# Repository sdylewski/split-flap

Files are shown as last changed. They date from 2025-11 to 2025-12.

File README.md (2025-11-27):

-# Split-Flap
+# Split-Flap
+
(   )
+
+Split Flap Display
+
+This fork builds on the brilliant [original project](https://github.com/Dave19171/split-flap) by
+[David Königsmann](https://github.com/Dave19171) and adds a modern web UI, OTA updates,
+message scheduling, a WiFi setup portal, diagnostics and numerous firmware
+improvements while keeping the 3D-printable mechanical design.
+
+## Feature Highlights
+
+- Multi-mode web UI (text, countdown, date, clock) with scheduling and OTA
+- Non-blocking ESPMaster firmware that keeps HTTP requests responsive
+- Built-in WiFi setup portal (AP mode) plus optional static IP/direct mode
+- LED error indicator (ESP-01S), page-load debug logs and copyable serial logs
+- Message splitting for long strings, newline support and REST endpoints
+
+## Documentation
+
+All project documentation now lives under [`docs/`](./docs). Start here:
+
+| Topic | Description |
+| --- | --- |
+| [`docs/README.md`](./docs/README.md) | Docs hub + quick start |
+| [`docs/printing.md`](./docs/printing.md) | BOM, screw list, printed parts, flap tips |
+| [`docs/hardware-build.md`](./docs/hardware-build.md) | PCB soldering, unit assembly, enclosure |
+| [`docs/software.md`](./docs/software.md) | Firmware setup, calibration, debugging, usage |
+| [`docs/SplitFlapInstructions.md`](./docs/SplitFlapInstructions.md) | Legacy PDF converted to Markdown |
+
+## Repository Structure
+
+```
+.
+├── docs/                 # Documentation hub
+├── ESPMaster/            # ESP-01S firmware + web assets
+├── Unit/                 # Arduino Nano unit firmware
+├── EEPROM_Write_Offset/  # Utility sketch for per-unit offsets
+├── PCB/                  # Schematics, Gerbers, pick-and-place
+├── Images/               # Reference photos used in docs
+└── Instructions/         # Original PDF (kept for reference)
+```
+
+## Getting Started
+
+1. Review [`docs/printing.md`](./docs/printing.md) to print and source parts
+2. Follow [`docs/hardware-build.md`](./docs/hardware-build.md) to assemble the
+   PCBs, units and enclosure
+3. Configure firmware, calibrate offsets and explore the web UI using
+   [`docs/software.md`](./docs/software.md)
+
+Have improvements or fixes? Contributions are welcome—open an issue or a pull
+request and help the display flip even better!

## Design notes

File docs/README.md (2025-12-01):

# Split-Flap Documentation

> This project builds on outstanding prior work:
> - Original split-flap design by [David Königsmann](https://github.com/Dave19171/split-flap)
> - Additional software updates by [JonnyBooker](https://github.com/JonnyBooker/split-flap)
> - Firmware/UI enhancements by [scientress](https://github.com/scientress/split-flap)

**What’s new in this fork**

- Arduino IDE 2.x support (LittleFS workflow + updated library guidance)
- Expanded debugging (startup log page, error status panel, page-load log,
  copyable serial log, ESP-01S LED indicator)
- Stability fixes for the web UI, `/settings` endpoint and I²C diagnostics
- Consolidated documentation under `docs/` with separate printing, hardware and
  software guides

Welcome to the documentation hub for the split-flap display. The goal of this
folder is to provide a single place for build instructions, firmware guidance
and reference material. If you are new to the project, follow the quick start
below and then dive into the topic that is most relevant for you.

## Quick Start

1. **Print & source parts** – make sure you have all printed parts, screws and
   electronic components ready. See [`printing.md`](./printing.md).
2. **Assemble the hardware** – solder the PCBs, build the units, wire
   everything and close the enclosure. See [`hardware-build.md`](./hardware-build.md).
3. **Configure the software** – flash the ESPMaster firmware, calibrate each
   unit, set DIP switches and verify/debug the system. See
   [`software.md`](./software.md).

### BOM & Purchasing Notes

- The recommended controller is the **ESP-01S** (not the original ESP-01). The
  ESP-01S has better WiFi performance, and routes its onboard blue LED to GPIO2 (so the firmware can drive the
  error indicator without tying up TX/RX) 
- For a consolidated list of screws, inserts, printed parts and electronics,
  refer to [`printing.md`](./printing.md).

## Repository Layout

| Path | Description |
| --- | --- |
| `docs/` | Documentation hub (this folder) |
| `ESPMaster/` | ESP-01S firmware and web assets |
| `Unit/` | Arduino Nano firmware for each flap unit |
| `EEPROM_Write_Offset/` | Basic utility sketch to manually set per-unit offsets |
| `InteractiveCalibration/` | Interactive calibration tool with step-by-step guidance |
| `PCB/` | Schematics, Gerbers and pick-and-place files |
| `Images/` | Reference photos used by the docs |

## Document Map

| Document | Purpose |
| --- | --- |
| [`printing.md`](./printing.md) | BOM, screw list, printed part manifest and flap printing tips |
| [`hardware-build.md`](./hardware-build.md) | PCB soldering, unit assembly and enclosure build |
| [`software.md`](./software.md) | Firmware setup, calibration, DIP switches, debugging and usage |
| [`interactive-calibration.md`](./interactive-calibration.md) | Guide for using the Interactive Calibration tool |
| [`SplitFlapInstructions.md`](./SplitFlapInstructions.md) | Legacy PDF content converted to Markdown for archival/reference |

## Feature Highlights

- Web UI with scheduling, OTA updates and diagnostics
- Non-blocking firmware that keeps the web server responsive
- Built-in WiFi setup portal and optional static IP mode
- Detailed debug tooling: startup page, error log, serial log viewer and LED
  error indicator (ESP-01S only)

## Need Help?

- Hardware or mechanical questions → start with [`printing.md`](./printing.md)
  and [`hardware-build.md`](./hardware-build.md).
- Firmware configuration or troubleshooting → see [`software.md`](./software.md).
- Historical instructions → consult [`SplitFlapInstructions.md`](./SplitFlapInstructions.md).

Spotted an issue or have an improvement? Feel free to open an issue or pull
request on the repository. Contributions are welcome!

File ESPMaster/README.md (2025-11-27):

# ESPMaster Scott Version - Modifications

This is a modified version of the ESPMaster code with improvements for better web server responsiveness and debugging capabilities.

## Major Changes from the Base v2.3.0 Release

- Added LED error indication that continuously blinks when critical errors are detected (e.g., WiFi connection failed).
- Replaced blocking calls (notably `waitForSync()` and `delay()`) with non-blocking loops that `yield()` so the HTTP server stays responsive.
- Introduced per-phase timeouts (WiFi, NTP sync, flap updates, filesystem waits) to prevent indefinite hangs.
- Expanded debug output, including a status string that traces the current setup phase over serial and mirroring of those messages to the web UI.
- Added a WiFi strength indicator (RSSI + qualitative label) on the main interface so you can spot reception issues without attaching a serial cable.
- Hardened `ServiceFlapFunctions` with cooperative timing so lengthy display updates do not starve the rest of the system.

## Key Changes

### 1. LED Error Indication
The onboard blue LED on the ESP-01S will continuously blink when a critical error is detected (e.g., WiFi connection failed). This provides a simple visual indicator for troubleshooting.

**ESP-01S Only**
- This feature only works with the **ESP-01S** module.
- The ESP-01S has its onboard blue LED on GPIO 2 (not on TX/RX lines), which allows it to be used for error indication while keeping the TX/RX lines dedicated to I2C communication with the split-flap units.
- The original ESP-01 has its LED on GPIO 1 (TX), which conflicts with I2C communication, so this LED feature is not supported on ESP-01.

### 2. Non-Blocking NTP Sync
- Replaced blocking `waitForSync()` with a non-blocking timeout-based approach
- 30-second timeout prevents indefinite hanging
- Calls `yield()` during sync to allow web server to process requests
- System continues even if NTP sync fails

### 3. Web Server Responsiveness Improvements
- Added `yield()` calls in all blocking `while` loops in `ServiceFlapFunctions.ino`
- Replaced blocking `delay()` calls with non-blocking timing using `millis()`
- Added 30-second timeouts to prevent infinite hangs when waiting for display
- Web server can now process requests even while display is updating

### 4. Enhanced Debugging
- Added `DEBUG:` status messages throughout setup
- Debug status string tracks current initialization phase
- More verbose logging for troubleshooting
- **Debug Mode** (`DEBUG_ENABLE`): When enabled, provides comprehensive debugging features:
  - **Startup Debug Page**: Shows initialization log during boot (accessible before main UI loads)
  - **Error Status Panel**: Displays JavaScript errors, network errors, and page load issues at the top of the main page
  - **Page Load Debug Log**: Shows debug messages during page initialization (collapsible viewer)
  - **Serial Debug Log**: Real-time serial output at the bottom of the main page with hide/show toggle
- All debug features can be enabled/disabled via `/enable-debug-mode` and `/exit-debug-mode` endpoints

### 5. WiFi Strength Indicator
- `getCurrentSettingValues()` now samples RSSI multiple times and returns both the raw dBm value and connection state.
- The web UI renders this as a color-coded "Excellent/Very Good/…/Very Weak" status line next to the WiFi details.
- Use this to diagnose poor placement or antenna issues; values worse than about -80 dBm usually cause missed OTA packets and unreliable message pushes.

## Hardware Requirements

- **ESP-01S Module**: Required for LED error indication feature
- The onboard blue LED on GPIO 2 is used automatically (no external wiring needed)

## Version

- **Version**: 2.3.0-Scott
- **Based on**: split-flap-scientress ESPMaster v2.3.0

## Files Modified

1. **ESPMaster.ino**
   - Added LED error indication function
   - Non-blocking NTP sync with timeout
   - Enhanced debug logging

2. **ServiceFlapFunctions.ino**
   - Added `yield()` calls in all blocking loops
   - Non-blocking delays with `yield()`
   - Timeout protection for display wait loops

## Benefits

- **Web interface remains responsive** even when display is updating
- **Visual error indication** via LED continuous blink on critical errors
- **No more indefinite hangs** from NTP sync or display waits
- **Better error detection** through LED indication and comprehensive debug messages

## Troubleshooting

If the web page still doesn't load:
1. Check if the LED is continuously blinking (indicates a critical error like WiFi connection failure)
2. Enable `SERIAL_ENABLE` to see detailed debug messages
3. Check the debug log on the web interface (if accessible) or serial output
4. Verify WiFi connection and credentials

If LED doesn't work:
- Ensure you're using an ESP-01S module (not the original ESP-01)
- The LED feature is automatically enabled when `ESP01S_LED_ENABLE` is set to `true` in the code

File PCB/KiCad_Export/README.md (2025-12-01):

# KiCad Project - Split Flap Display PCB

This directory contains the KiCad project files converted from EasyEDA source files.

## Files

- `SplitFlap.kicad_pro` - Main KiCad project file
- `SplitFlap.kicad_sch` - Schematic file
- `SplitFlap.kicad_pcb` - PCB layout file
- `SplitFlap.kicad_sym` - Symbol library
- `EasyEDA.pretty/` - Footprint library directory

## Opening in KiCad

1. **Install KiCad 6.x or later** (required for these files)
   - Download from: https://www.kicad.org/download/

2. **Open the project:**
   - Launch KiCad
   - File → Open Project
   - Navigate to this directory and open `SplitFlap.kicad_pro`

3. **Add libraries (if needed):**
   - The footprint library `EasyEDA.pretty` should be automatically detected
   - If not, go to Preferences → Manage Footprint Libraries → Project Specific Libraries
   - Add the `EasyEDA.pretty` directory

## Assigning 3D Models to Components

To get a complete 3D STEP file with all components, you need to assign 3D models to each footprint. The components are already placed on the PCB, but their 3D models need to be linked.

### Method 1: Using KiCad's 3D Viewer (Recommended)

1. **Open the PCB Editor:**
   - In KiCad, click on the PCB Editor icon or open `SplitFlap.kicad_pcb`

2. **View in 3D:**
   - Click the **3D Viewer** button (or View → 3D Viewer)
   - This shows which components have 3D models and which don't

3. **Assign 3D Models to Footprints:**
   - Right-click on a component footprint → **Properties**
   - Click the **3D Models** tab
   - Click **Add 3D Model**
   - Browse to find the 3D model file (`.step`, `.wrl`, or `.obj` format)
   - Adjust position/rotation if needed
   - Click **OK**

4. **Download 3D Models:**
   - **GrabCAD**: https://grabcad.com/library (search by part number)
   - **3D ContentCentral**: https://www.3dcontentcentral.com/
   - **SnapEDA**: https://www.snapeda.com/ (free account required)
   - **KiCad 3D Model Library**: Check if models exist in KiCad's default library
   - **Component Manufacturers**: Many provide STEP files on their websites

### Method 2: Batch Assign Using Footprint Editor

1. **Open Footprint Editor:**
   - Tools → Footprint Editor

2. **Edit Each Footprint:**
   - File → Open Footprint
   - Navigate to `EasyEDA.pretty/` and open the footprint
   - Click the **3D Models** tab
   - Add the 3D model file
   - Save the footprint

3. **Update PCB:**
   - The changes will automatically apply to all instances of that footprint on the PCB

### Method 3: Using EasyEDA Component Library (if available)

The converter may have created references to 3D models. Check if they exist:
- Look in the footprint files in `EasyEDA.pretty/` for 3D model references
- The converter creates references like: `${KICAD6_3DMODEL_DIR}/EasyEDA.3dshapes/footprint_name.wrl`
- You may need to download these models from EasyEDA/LCSC or find equivalent models

## Exporting 3D STEP File

Once 3D models are assigned:

1. **Open the PCB Editor:**
   - In KiCad, click on the PCB Editor icon or open `SplitFlap.kicad_pcb`

2. **Verify 3D Models:**
   - Open 3D Viewer (View → 3D Viewer)
   - Check that components show 3D models (not just flat pads)
   - If components appear flat, they need 3D models assigned

3. **Export STEP file:**
   - Go to **File → Export → STEP...**
   - Choose a location and filename (e.g., `SplitFlap_PCB.step`)
   - **Important**: Check the options:
     - ✅ Include 3D models for components
     - ✅ Include board outline
   - Click **Save**

4. **The STEP file will include:**
   - PCB board outline
   - All component footprints positioned correctly
   - 3D models of components (if assigned)

## Key Components on This PCB

Based on the BOM, main components include:
- **ULN2003A** (U4) - DIP-16 package - Common 3D models available
- **L7805CV** (U3) - TO-220 package - Standard regulator, models widely available
- **AMS1117-3.3** (U9) - SOT-223 package - Common LDO, models available
- **Arduino Nano** (U1) - Custom footprint - May need custom model or approximate
- **ESP-01S** (U2) - Custom WiFi module - May need custom model
- **JST Connectors** (U6, U7, U8, U10) - XH series - Models available from JST
- **DIP Switch** (SW1) - Custom footprint - May need approximate model
- **Passive components** (C0805, R0805, etc.) - Standard SMD - Models widely available

### Quick Tips for Finding 3D Models:

1. **Standard packages** (0805, SOT-23, TO-220, etc.):
   - Search by package name on GrabCAD or 3D ContentCentral
   - KiCad's default library may have some

2. **Specific parts** (ULN2003A, L7805CV):
   - Search by part number on manufacturer websites
   - Many have STEP files in their product pages

3. **Custom parts** (Arduino Nano, ESP-01S):
   - Arduino: Official Arduino website or GrabCAD
   - ESP-01S: Ai-Thinker website or approximate with similar ESP module models

4. **Connectors** (JST XH series):
   - JST provides 3D models on their website
   - Search "JST XH 3D model STEP"

## Notes

- The conversion created 3 messages during PCB conversion - check the User.Cmts layer in the PCB editor for details
- Some manual adjustments may be needed for component 3D models
- Components are already placed on the PCB from the EasyEDA conversion
- You only need to assign 3D models - the physical placement is already correct
- The original EasyEDA source files are in `../EasyEDA_Source/`

## Original Source Files

- PCB: `../EasyEDA_Source/PCB_PCB_Splitflap_2022-06-04.json`
- Schematic: `../EasyEDA_Source/SCH_SplitFlap_2022-06-04.json`
- BOM: `../BOM_PCB_Splitflap_2022-03-11.csv`

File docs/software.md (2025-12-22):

# Software Configuration & Usage

This guide covers everything required to configure the firmware, calibrate the
units, and operate/debug the split-flap display.

## 1. Firmware Components

| Component | Location | Purpose |
| --- | --- | --- |
| ESPMaster (ESP-01S) | `ESPMaster/` | Web server, WiFi, scheduler, diagnostics |
| Unit firmware (Nano) | `Unit/Unit.ino` | Drives each flap drum |
| Interactive Calibration | `InteractiveCalibration/InteractiveCalibration.ino` | **Recommended:** Guided calibration tool with automatic offset calculation |
| EEPROM offset tool | `EEPROM_Write_Offset/EEPROM_Write_Offset.ino` | **Backup:** Basic utility to manually set per-unit zero position |

## 2. Toolchain & Libraries

1. Install the ESP8266 board package in Arduino IDE  
   [Guide](https://randomnerdtutorials.com/how-to-install-esp8266-board-arduino-ide/)
2. Install the following libraries via Library Manager (versions work on IDE 1.x
   **and** 2.x):
   - ArduinoJson 7.0.4 (any 7.x)
   - ESPAsyncWebSrv 1.2.7 (+ ESPAsyncTCP / AsyncTCP dependencies)
   - NTPClient 3.2.1
   - ezTime 0.8.3
   - LinkedList 1.3.3
   - WiFiManager 2.0.17
3. Install the LittleFS upload plugin:
   - **IDE 2.x:**
     1. Download the latest `.vsix` file from
        https://github.com/earlephilhower/arduino-littlefs-upload/releases
     2. Copy the `.vsix` file to the Arduino IDE plugins folder:
        - **macOS/Linux:** `~/.arduinoIDE/plugins/`
        - **Windows:** `C:\Users\<your_username>\.arduinoIDE\plugins\`
        - Create the `plugins` folder if it doesn't exist
     3. Restart Arduino IDE 2.x completely
     4. **IMPORTANT:** The plugin does NOT appear in the Tools menu. To access it:
        - Press `⌘ + Shift + P` (macOS) or `Ctrl + Shift + P` (Windows/Linux) to open the Command Palette
        - Type "Upload LittleFS" and select the command
        - The plugin will appear in the command palette (see upload steps below)
   - **IDE 1.x:** install the legacy plugin and use *Tools → ESP8266 LittleFS
     Data Upload*.

> **Important:** Before uploading LittleFS, always close the Serial Monitor. The uploader needs exclusive access to the serial port. If you see "Resource busy" or "could not open port" errors, close the Serial Monitor and any other programs using the port, then retry.

> **Note:** The codebase works unmodified on Arduino IDE 2.x. If you encounter
> compilation issues, update libraries to their latest minor versions.

## 3. Upload Sequence

1. **LittleFS assets**
   - Open `ESPMaster/ESPMaster.ino` in Arduino IDE
   - **Important:** Close the Serial Monitor if it's open (the serial port must be free)
   - Select *Generic ESP8266 Module* from the board menu
   - Select the correct COM port for your ESP-01S programmer
   - **IDE 2.x:** 
     - **IMPORTANT:** Press `⌘ + Shift + P` (macOS) or `Ctrl + Shift + P` (Windows/Linux) to open the Command Palette
     - Type "Upload LittleFS" and select it (the plugin does NOT appear in the Tools menu)
   - **IDE 1.x:** Use *Tools → ESP8266 LittleFS Data Upload* from the menu
   - Wait for the upload to complete (you'll see "LittleFS Image Uploaded" in the output)
   - **Important:** After LittleFS upload completes, unplug and replug the ESP-01S programmer to reset the device before proceeding to firmware upload
2. **ESPMaster firmware**
   - After LittleFS completes and you've power-cycled the ESP-01S, ensure it's in programming mode (GPIO0 LOW)
   - Use *Upload* to flash the sketch itself
   - If upload fails with "device disconnected" errors, try lowering the upload speed to 115200 baud in *Tools → Upload Speed*
3. **Unit firmware**
   - For each Arduino Nano, open `Unit/Unit.ino`
   - Select *Arduino Nano* (use *ATmega328P (Old Bootloader)* if uploads fail)
   - Flash the sketch
4. **Calibration tools** (see Calibration Workflow section below)
   - **Recommended:** Use `InteractiveCalibration/InteractiveCalibration.ino` for guided calibration
   - **Backup:** Use `EEPROM_Write_Offset/EEPROM_Write_Offset.ino` if you need to manually enter a known offset value

## 4. Over-The-Air (OTA) Updates

OTA allows you to update the ESPMaster firmware wirelessly over WiFi without physically connecting the ESP-01S to your computer. This is convenient for deployed displays or when the ESP-01S is difficult to access.

### 4.1 Enabling OTA

1. **Enable OTA in code:**
   - In `ESPMaster.ino`, set `#define OTA_ENABLE true`
   - Optionally change the OTA password (default is `"1234"`):
     ```cpp
     const char* otaPassword = "1234";  // Change this to your desired password
     ```
   - Upload the firmware normally (via USB) with OTA enabled

2. **Activate OTA mode:**
   - Once the ESP-01S is running and connected to WiFi, open the web interface
   - Click the "OTA Update" link (only visible when `OTA_ENABLE` is `true`)
   - Confirm the action - this puts the ESP-01S into OTA mode
   - A confirmation page will appear

### 4.2 Uploading via OTA

1. **In Arduino IDE:**
   - Open `ESPMaster/ESPMaster.ino`
   - Make your code changes
   - Go to *Tools → Port* and look for a new port named **"Split-Flap-OTA at [IP address]"**
     - Example: "Split-Flap-OTA at 192.168.0.111"
     - This appears as a network port, not a USB serial port
     - If you don't see it, try refreshing the port list or ensure OTA mode was activated
   - Select this OTA port
   - Click *Upload* as normal - the firmware will be uploaded over WiFi
   - Watch the progress in the Arduino IDE status bar

2. **After upload:**
   - The ESP-01S will automatically reboot
   - Wait a few seconds, then refresh the web interface
   - The device should be running the new firmware

### 4.3 OTA Limitations & Notes

- **LittleFS updates:** OTA can update the firmware sketch, but **cannot update LittleFS files** (web assets). To update `index.html`, `script.js`, or `style.css`, you must use the USB LittleFS upload method.
- **First-time setup:** OTA must be enabled and uploaded via USB at least once before it can be used wirelessly.
- **WiFi required:** OTA only works when the ESP-01S is connected to WiFi. If WiFi is down, you must use USB.
- **Password protection:** The default password is `"1234"`. Change it in the code for security.
- **Stability:** OTA works best with strong WiFi signal. Poor signal can cause upload failures or corruption.

### 4.4 Troubleshooting OTA

- **OTA port not appearing:**
  - Ensure OTA mode was activated via the web interface (click "OTA Update" link)
  - Check that the ESP-01S is on the same WiFi network as your computer
  - Try refreshing the Arduino IDE port list (close and reopen Tools → Port menu)
  - Verify OTA is enabled in code (`#define OTA_ENABLE true`)
- **Upload fails:**
  - Check WiFi signal strength (RSSI should be better than -80 dBm via web UI)
  - Ensure no firewall is blocking the connection
  - Try activating OTA mode again via web interface
  - Move closer to the router for better signal
  - As a fallback, use USB upload
- **Device unresponsive after OTA:**
  - Power cycle the ESP-01S - sometimes a manual reset is needed after OTA updates
  - Check serial monitor for error messages

## 5. Configuration Options

At the top of `ESPMaster.ino`, configurable `#define` blocks control behaviour:

- `WIFI_USE_DIRECT` – set `true` for infrastructure WiFi, `false` for AP setup
- `WIFI_STATIC_IP` – enable to assign a static IP (update the IP/DNS settings
  directly below)
- `ESP01S_LED_ENABLE` – toggles the ESP-01S onboard LED error indicator
- `SERIAL_ENABLE`, `OTA_ENABLE`, `UNIT_CALLS_DISABLE` – enable serial logging,
  OTA updates and ESP-only testing respectively
- `DEBUG_ENABLE` – exposes the startup debug page, error status panel, page-load
  log and serial log in the web UI

Other important settings:

- `timezoneString` – set to a TZ database name (e.g. `America/Los_Angeles`)
- Clock/date formatting – see https://github.com/ropg/ezTime#datetime
- WiFi credentials for direct mode: update `wifiDirectSsid` and
  `wifiDirectPassword`

## 6. Calibration Workflow

### 6.1 Set Zero Position Offset

**Important:** Disconnect the unit from all other units and the I2C bus. Only connect power and the USB serial cable. Serial communication can be unreliable when multiple units are connected due to power draw, I2C bus interference, or electrical noise.

#### Option A: Interactive Calibration (Recommended)

The Interactive Calibration tool provides a guided, step-by-step process that automatically calculates the optimal offset using statistical methods. This is the recommended method for accurate calibration.

**Steps:**

1. **Upload the calibration tool:**
   - Open `InteractiveCalibration/InteractiveCalibration.ino` in Arduino IDE
   - Select *Arduino Nano* board (use *ATmega328P (Old Bootloader)* if uploads fail)
   - Upload the sketch to the unit

2. **Open Serial Monitor:**
   - Set baud rate to **9600**
   - Set line ending to **"Newline"** or **"Both NL & CR"**
   - **Note:** You may need to press the reset button on the Arduino after upload for serial output to work correctly

3. **Follow the interactive prompts:**
   - The tool will automatically home the unit
   - It will ask you to type the letter you see (to determine starting position)
   - For each of 5 measurements, it will rotate slowly - press Enter when the next letter just flips
   - The tool calculates the optimal offset using linear regression from all measurements
   - The offset is automatically written to EEPROM when complete

4. **Complete the calibration:**
   - After the 5 measurements, the tool displays the calculated offset
   - The offset is saved to EEPROM automatically
   - You can now upload `Unit.ino` - the calibration is complete

**For detailed instructions, see:** [`docs/interactive-calibration.md`](./interactive-calibration.md)

#### Option B: Manual Entry (Backup Method)

The `EEPROM_Write_Offset.ino` tool is a simple backup method if you already know the offset value or want to manually enter it. This method requires you to determine the correct offset value yourself through trial and error.

**Steps:**

1. **Upload the utility:**
   - Open `EEPROM_Write_Offset/EEPROM_Write_Offset.ino` in Arduino IDE
   - Upload to the unit

2. **Open Serial Monitor:**
   - Set baud rate to **9600**
   - You may need to restart the serial monitor or press reset to see output

3. **Enter offset value:**
   - Type a number (typically around 50 steps) and press Enter
   - Test the unit with `Unit.ino` to see if the blank flap aligns correctly
   - Repeat with different values until satisfied

4. **Upload Unit.ino:**
   - Once the offset is correct, upload `Unit.ino` to use the calibrated unit

**Note:** This method is less accurate than Interactive Calibration and requires manual testing to find the correct value.
2. **Configure Unit Addresses**
   - DIP switch (SW1) bits: SW1=bit3 (value 8)…SW4=bit0 (value 1)
   - Switch **up = ON = 1**, **down = OFF = 0**
   - Address = SW4×1 + SW3×2 + SW2×4 + SW1×8
   - Units must be sequential starting at 0
   - Verify via the `/i2c-scan` endpoint in the ESP web UI
3. **Integration Test**
   - Power the full chain
   - Use the web UI text mode or schedule messages
   - Confirm all units respond (watch serial/I²C diagnostics)

## 7. Web Interface & Usage

- **Text mode:** send ad-hoc messages; long messages auto-split or honour `\n`
- **Countdown / date / clock modes:** switch via the web UI
- **Scheduling:** queue messages with timestamps or “show indefinitely”
- **WiFi strength indicator:** view RSSI + qualitative label on the settings
  panel
- **Log viewer:** shows the last 50 serial log entries and can copy to clipboard

## 8. Debugging Tools

### 8.1 Web UI diagnostics

- **Error status panel:** shows network/JavaScript errors at the top of the page
- **Page load debug log:** records lifecycle events (DOMContentLoaded, AJAX
  statuses, JSON parsing errors)
- **Serial log viewer:** mirrors the circular buffer from the ESP firmware with
  hide/show toggle and “Copy Full Log” button
- **Startup debug page:** accessible when `DEBUG_ENABLE` is true; shows the full
  boot log before redirecting to the main UI

### 8.2 LED indicator (ESP-01S only)

- Continuous blinking = critical error (e.g., WiFi connection failed)
- Requires `ESP01S_LED_ENABLE` to remain `true` and an ESP-01S module (LED on
  GPIO2, active LOW)

### 8.3 Serial logging

Enable `SERIAL_ENABLE` for verbose firmware logs. Useful during calibration or
when diagnosing I²C issues (`ServiceFlapFunctions.ino` reports error codes,
timeouts, sleeping units, etc.).

## 9. Common Issues & Fixes

| Symptom | Recommendation |
| --- | --- |
| LittleFS upload fails: "Resource busy" or "could not open port" | Close the Serial Monitor and any other programs using the serial port, then retry. On macOS, you may need to quit and restart Arduino IDE if the port remains locked. |
| Upload fails: "device reports readiness to read but returned no data" or "device disconnected" | **ESP-01/ESP-01S programming mode:** Ensure GPIO0 is pulled LOW and the device is reset into programming mode. Many ESP-01 programmers have a button or switch for this. Try: 1) Lower upload baud rate to 115200 or 57600 in Tools menu, 2) Press and hold the programming button (if available) during upload, 3) Power cycle the ESP-01S and immediately start upload, 4) Check USB cable/programmer connection. |
| Web UI hangs on load | Ensure LittleFS assets were uploaded; check `/settings` endpoint logs |
| `/settings` times out | Confirm `webRequestActive` is not held true (long-running display updates); inspect serial log |
| Units unresponsive / `I2C error 2` | Verify DIP switch addresses, wiring continuity, and use `/i2c-scan` |
| Unit stuck in "busy" state (status 1) | 1) Use `/i2c-scan` endpoint to check all unit addresses, 2) Verify DIP switch on the stuck unit (no conflicts with other units), 3) Check if unit's stepper motor is physically stuck, 4) Power cycle the stuck unit, 5) Re-upload `Unit.ino` firmware to the stuck unit, 6) Check I2C wiring to that specific unit |
| Incorrect character after homing | Re-run EEPROM offset calibration for that unit |
| WiFi unstable | Try static IP or extend antenna (per community notes); verify RSSI via UI |
| LED indicator off | Confirm module is ESP-01S (original ESP-01 LED conflicts with I²C) |

## 10. Additional Resources

- [`docs/README.md`](./README.md) – documentation hub
- [`docs/hardware-build.md`](./hardware-build.md) – mechanical assembly steps
- [`docs/printing.md`](./printing.md) – BOM and printing instructions
- [`docs/SplitFlapInstructions.md`](./SplitFlapInstructions.md) – legacy detailed instructions

With the firmware configured and calibrated, you can rely on the web interface
for day-to-day control, scheduling and diagnostics. Happy flipping!

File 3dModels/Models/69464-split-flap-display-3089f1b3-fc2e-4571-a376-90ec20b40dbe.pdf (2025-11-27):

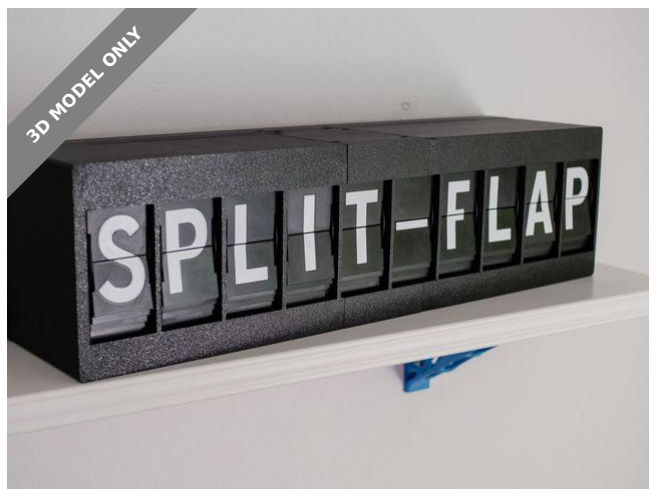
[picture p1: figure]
3D MODEL ONLY

# Summary

10-unit split-flap display. 3D-printed flaps. Modular.

Hobby & Makers (https://printables.com/model?categoryId=48) | > | Electronics (https://printables.com/model?categoryId=52)
Tags: display | splitflap | arduino | esp8266

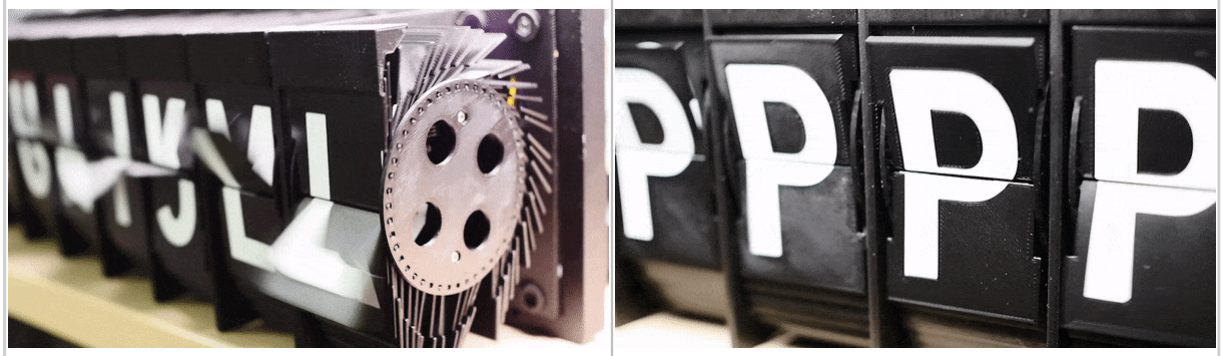
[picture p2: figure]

This split-flap display sets itself apart by being almost completely 3D-

printed. The flaps are printed by changing the color mid-print and mid-

layer. The case is also completely 3D-printed.

Video of the display in action (with sound):

https://www.reddit.com/r/3Dprinting/comments/o4boxk/

i_designed_my_own_splitflap_display/ (https://www.reddit.com/r/3Dprinting/comments/o4boxk/i_designed_my_own_splitflap_display/?context=3)

David Kingsman (https://printables.com/@DavidKingsman)

# Split-Flap Display

VIEW IN BROWSER (https://printables.com/model/69464-split-flap-display)

updated 20. 6. 2023 | published 20. 6. 2023

# Model files

It can be used as a date display, clock or anything really. It is connected to

the local network with an esp8266.

Josh Murrah (https://www.printables.com/@joshmurrah_539268) made an in-depth video about his build:

General info about display:

10 units (pcb design allows up to 16)

45 flaps per unit

Size: 513 mm x 136 mm x 138 mm

More info in the instruction manual (scroll all the way down to “other files”

in the files tab right here on prusaprinters).

GitHub: https://github.com/Dave19171/split-flap

Partially inspired by https://splitflap.home.blog/

•

•

•

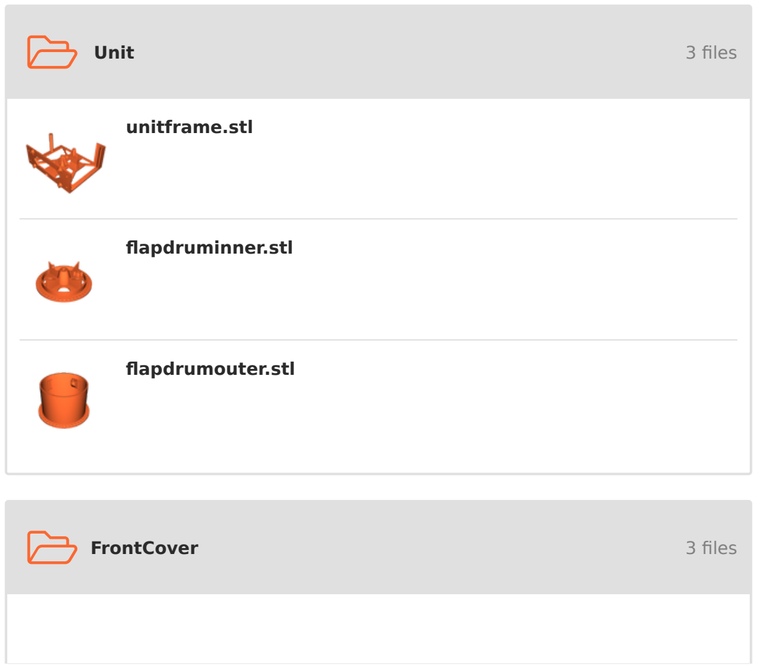
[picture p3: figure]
Unit; 3 files; FrontCover; unitframe.stl; flapdruminner.stl; flapdrumouter.stl

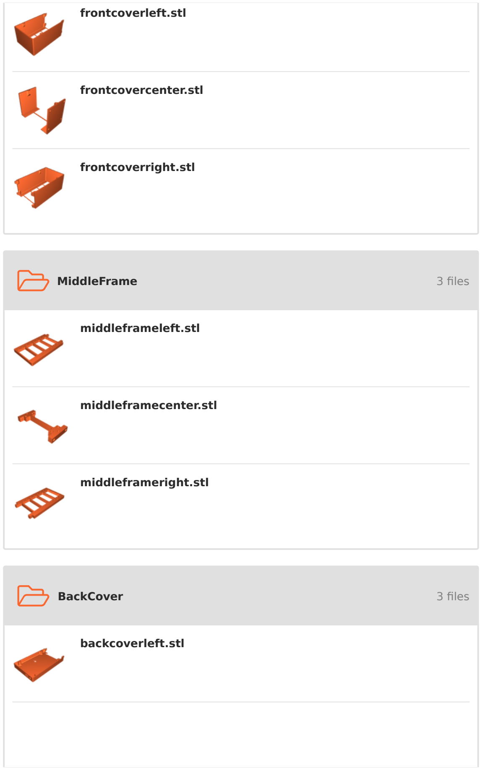
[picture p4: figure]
MiddleFrame; 3 files; BackCover; frontcoverleft.stl; frontcovercenter.stl; frontcoverright.stl; middleframeleft.stl; middleframecenter.stl; middleframeright.stl; backcoverleft.stl

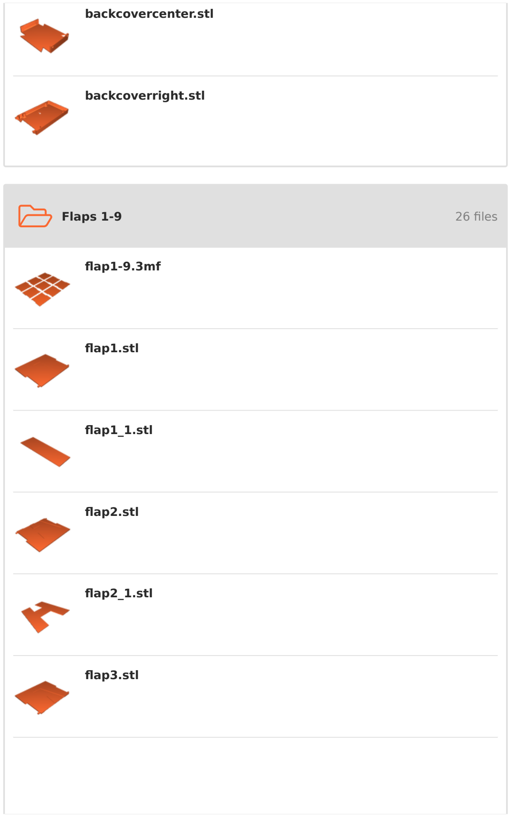
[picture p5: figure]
Flaps 1-9; 26 files; backcovercenter.stl; backcoverright.stl; flap1-9.3mf; flap1.stl; flap1_1.stl; flap2.stl; flap2_1.stl; flap3.stl

flap3_1.stl

flap32.stl

flap4.stl

flap4_1.stl

flap4_2.stl

flap5.stl

flap5_1.stl

flap5_2.stl

flap6.stl

flap6_1.stl

flap6_2.stl

flap7.stl

flap7_1.stl

flap7_2.stl

flap8.stl

flap8_1.stl

flap8_2.stl

flap9.stl

flap9_1.stl

flap9_2.stl

- Flaps 10-18 | 33 files

flap10-18.3mf

flap10.stl

flap10_1.stl

flap10_2.stl

flap11.stl

flap11_1.stl

flap11_2.stl

flap12.stl

flap12_1.stl

flap12_2.stl

flap13.stl

flap13_1.stl

flap13_2.stl

flap14.stl

flap14_1.stl

flap14_2.stl

flap14_3.stl

flap14_4.stl

flap15.stl

flap15_1.stl

flap15_2.stl

flap15_3.stl

flap15_4.stl

flap16.stl

flap16_1.stl

flap16_2.stl

flap16_3.stl

flap17.stl

flap17_1.stl

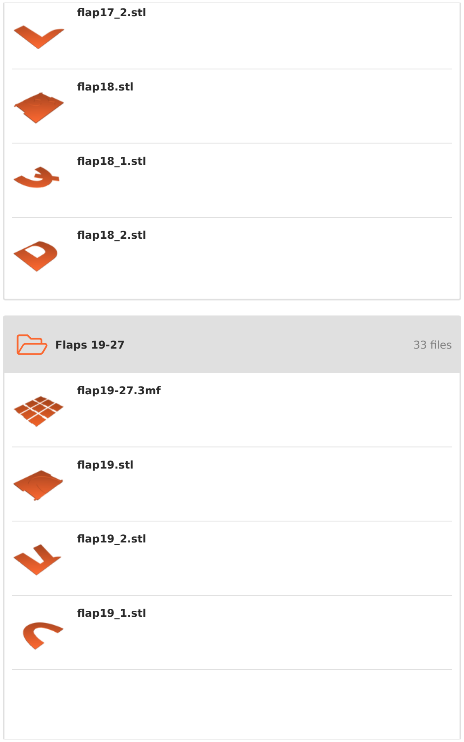
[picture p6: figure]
Flaps 19-27; 33 files; flap17_2.stl; flap18.stl; flap18_1.stl; flap18_2.stl; flap19-27.3mf; flap19.stl; flap19_2.stl; flap19_1.stl

flap20.stl

flap20_1.stl

flap20_2.stl

flap22_1.stl

flap21.stl

flap21_1.stl

flap21_2.stl

flap22.stl

flap22_2.stl

flap23.stl

flap23_1.stl

flap23_2.stl

flap23_3.stl

flap24.stl

flap24_1.stl

flap24_2.stl

flap24_3.stl

flap24_4.stl

flap25.stl

flap25_1.stl

flap25_2.stl

flap25_3.stl

flap25_4.stl

flap26.stl

flap26_1.stl

flap26_2.stl

flap27.stl

flap27_1.stl

flap27_2.stl

- Flap 28-36 no umlaute | 13 files

flap28-36_no_umlaut.3mf

flap28_no_um.stl

flap28_1_no_um.stl

flap28_2_no_um.stl

flap29_no_um.stl

flap29_1_no_um.stl

flap29_2_no_um.stl

flap30_no_um.stl

flap30_1_no_um.stl

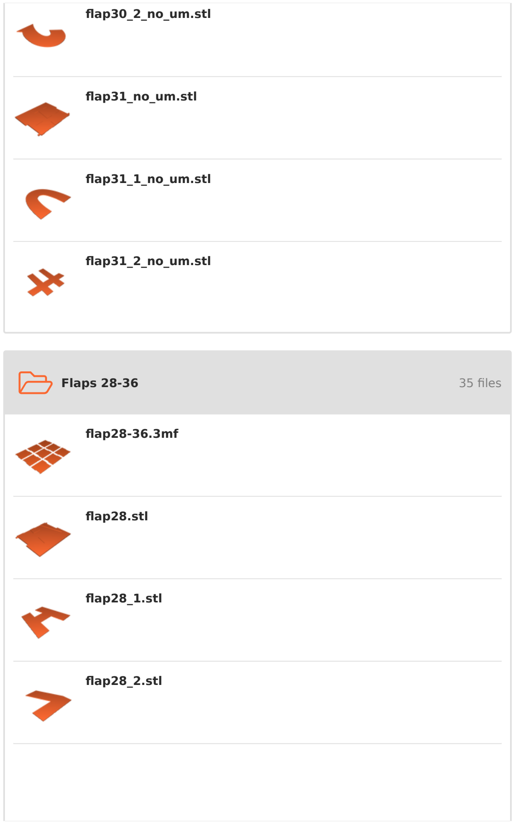
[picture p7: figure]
Flaps 28-36; 35 files; flap30_2_no_um.stl; flap31_no_um.stl; flap31_1_no_um.stl; flap31_2_no_um.stl; flap28-36.3mf; flap28.stl; flap28_1.stl; flap28_2.stl

flap29.stl

flap29_1.stl

flap29_2.stl

flap29_3.stl

flap29_4.stl

flap30.stl

flap30_1.stl

flap30_2.stl

flap30_3.stl

flap30_4.stl

flap31.stl

flap31_1.stl

flap31_2.stl

flap31_3.stl

flap31_4.stl

flap31_5.stl

flap32.stl

flap32_1.stl

flap32_2.stl

flap33.stl

flap33_1.stl

flap33_2.stl

flap34.stl

flap34_1.stl

flap34_2.stl

flap35.stl

flap35_1.stl

flap35_2.stl

flap36.stl

flap36_1.stl

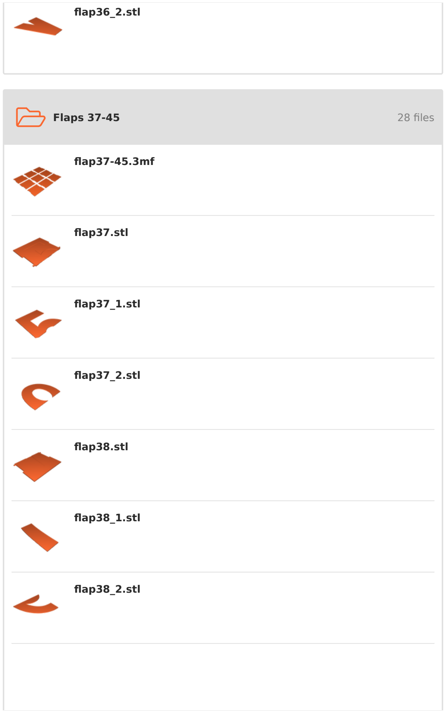
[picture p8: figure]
Flaps 37-45; 28 files; flap36_2.stl; flap37-45.3mf; flap37.stl; flap37_1.stl; flap37_2.stl; flap38.stl; flap38_1.stl; flap38_2.stl

flap39.stl

flap39_1.stl

flap39_2.stl

flap40.stl

flap40_1.stl

flap40_2.stl

flap41.stl

flap41_1.stl

flap41_2.stl

flap42.stl

flap42_1.stl

flap42_2.stl

flap43.stl

flap43_1.stl

flap44.stl

flap44_1.stl

flap44_2.stl

flap45.stl

flap45_1.stl

flap45_2.stl

# Other files

- If you want to make your own custom flaps
- If you want to make your own custom flaps

# License

This work is licensed under a

Creative Commons (4.0 International License)

Attribution-ShareAlike (http://creativecommons.org/licenses/by-sa/4.0/)

✖ | Sharing without ATTRIBUTION
✔ | Remix Culture allowed
✔ | Commercial Use
✔ | Free Cultural Works
✔ | Meets Open Definition

flap45_3.stl

assembly.step

flap_blank.step

flap_blank_do_not_print.stl

splitflapinstructions.pdf

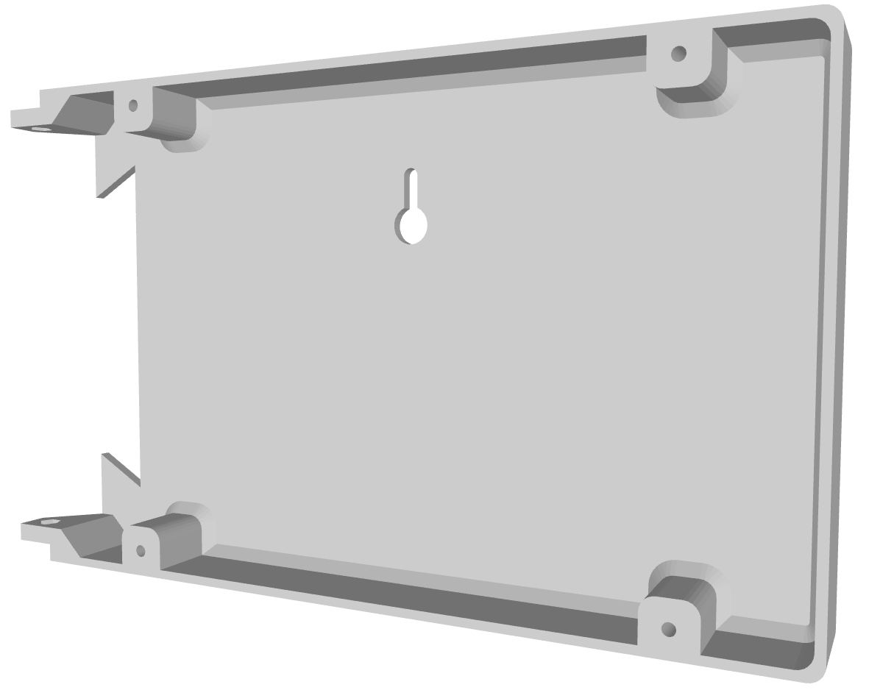
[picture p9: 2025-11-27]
docs/images/page_10_img_12.png

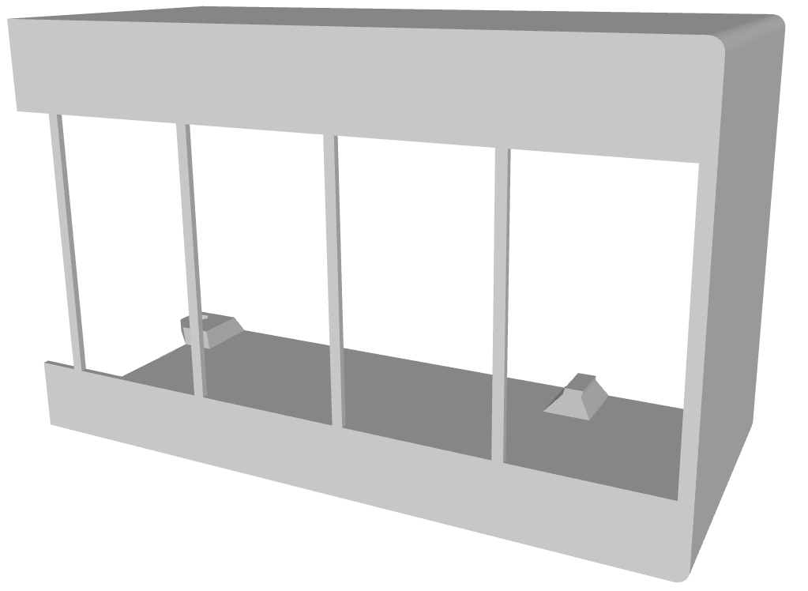
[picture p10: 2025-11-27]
docs/images/page_10_img_09.png

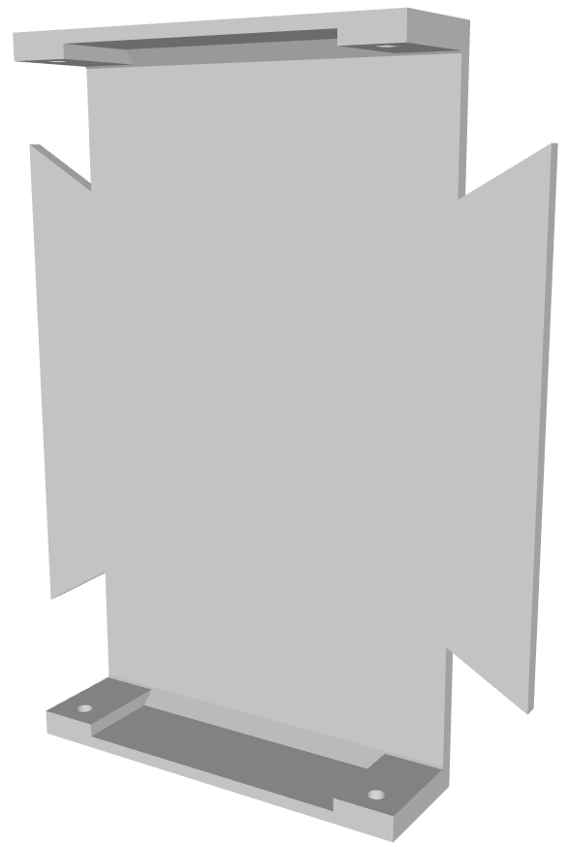
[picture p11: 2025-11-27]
docs/images/page_10_img_11.png

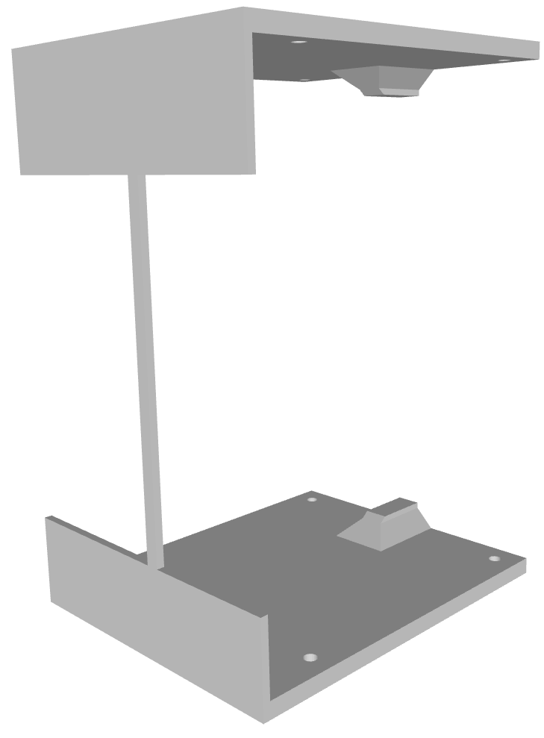
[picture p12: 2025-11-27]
docs/images/page_10_img_08.png

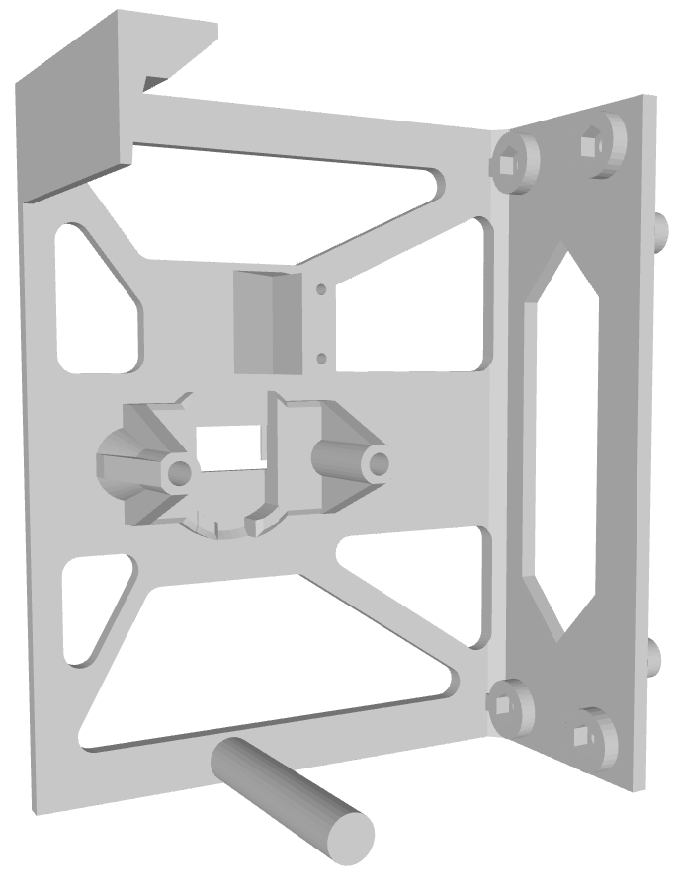
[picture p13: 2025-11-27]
docs/images/page_10_img_03.png

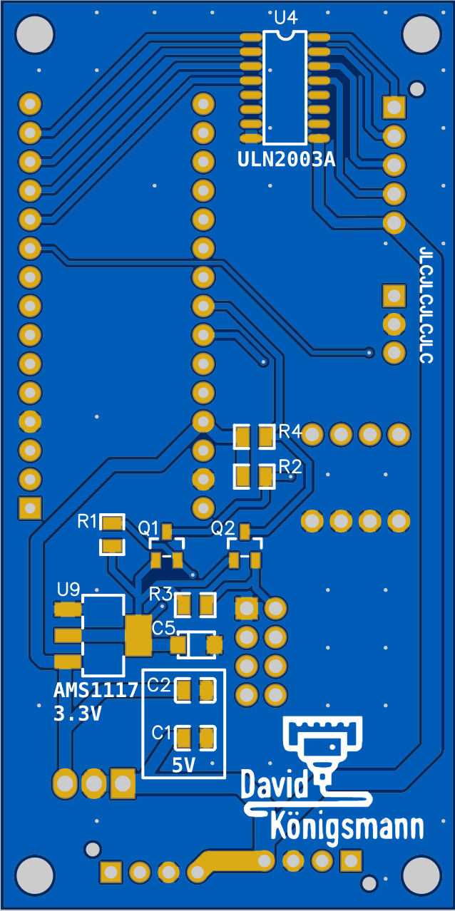
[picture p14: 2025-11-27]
docs/images/page_05_img_02.png

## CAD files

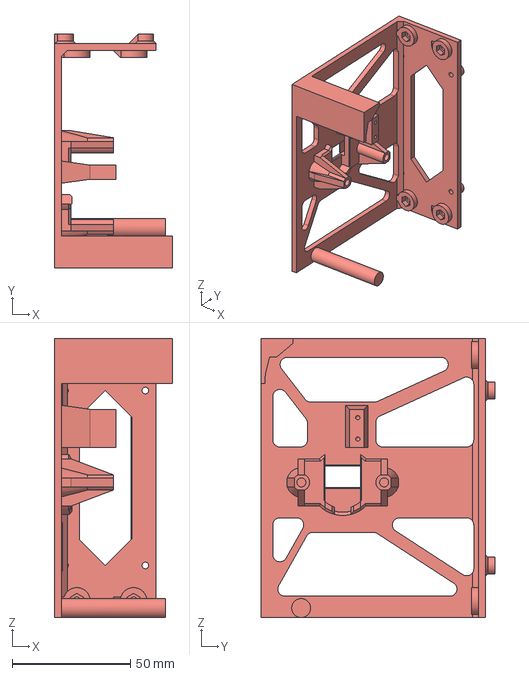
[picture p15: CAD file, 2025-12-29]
3dModels/Split-Flap_Assembly - Frame.step
50.0 x 99.0 x 118.0 mm

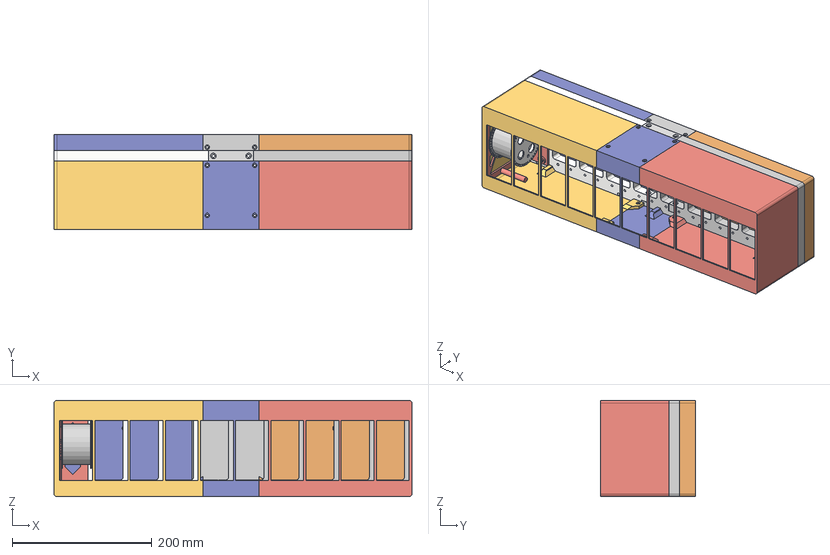
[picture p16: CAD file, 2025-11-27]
3dModels/Models/Assembly.step
513.2 x 135.8 x 138.0 mm
BigRotor
MiniRotor
Frame
HousingFrame
FrameBack
FrameFront

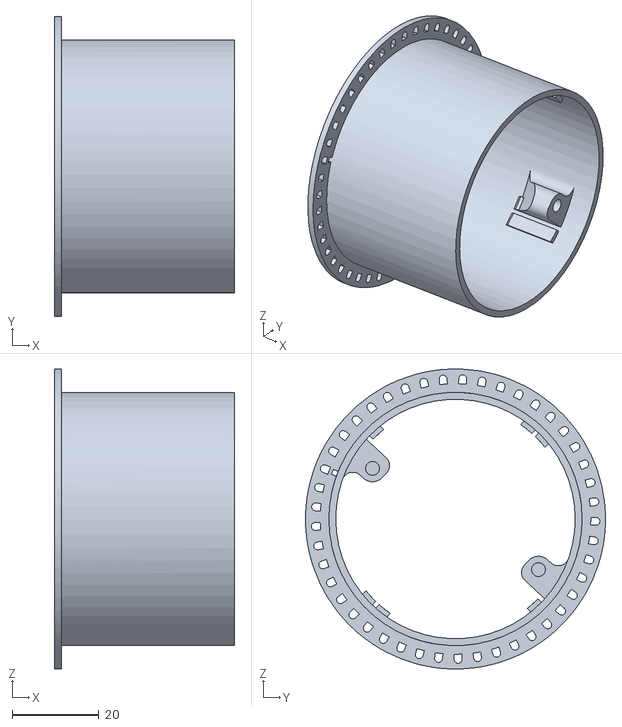
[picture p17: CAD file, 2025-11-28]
3dModels/Split-Flap_Assembly - BigRotor.stl
41.6 x 69.3 x 69.3

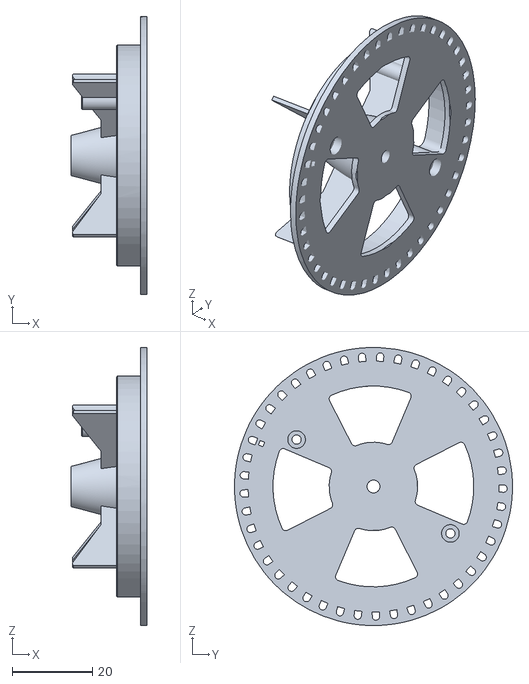
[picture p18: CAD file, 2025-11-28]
3dModels/Split-Flap_Assembly - MiniRotor.stl
19.0 x 69.3 x 69.3

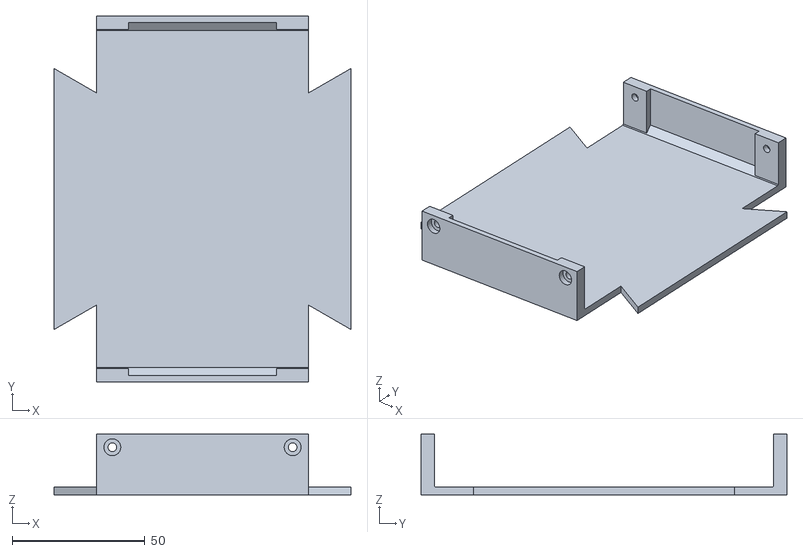
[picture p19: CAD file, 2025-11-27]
3dModels/Models/BackCover/BackCoverCenter.stl
112.0 x 138.0 x 23.0

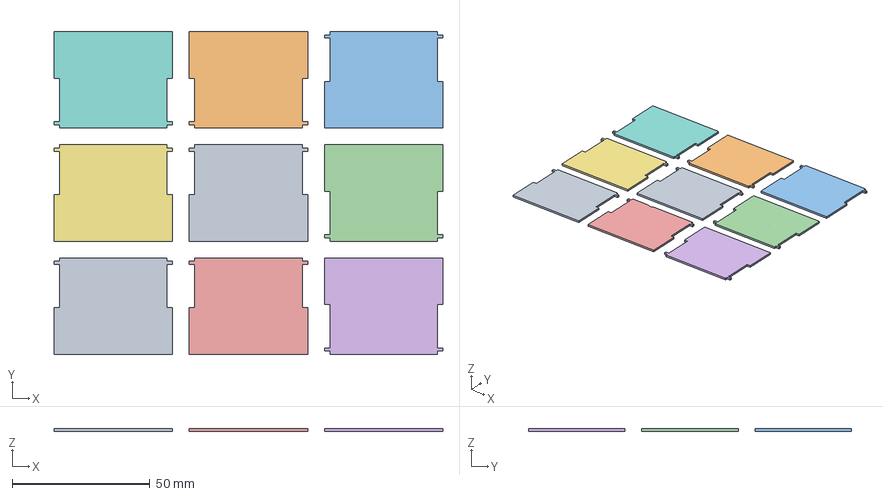
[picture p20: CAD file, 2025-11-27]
3dModels/Models/Flap 28-36 no umlaute/Flap28-36_no_Umlaut.3mf
141.0 x 117.0 x 1.00 mm
Flap32.stl
Flap33.stl
Flap34.stl
Flap35.stl
Flap36.stl
Flap31.2.stl
Flap30.1.stl
Flap29.3.stl
Flap28.1.stl

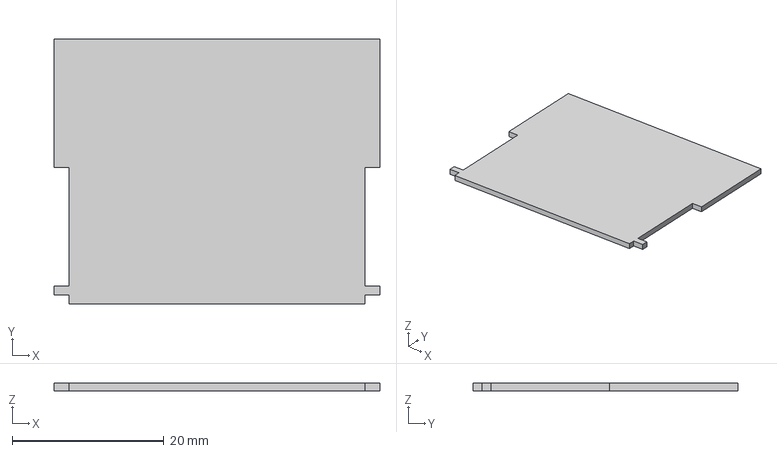
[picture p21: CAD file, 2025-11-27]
3dModels/Models/Flap_blank.step
43.0 x 35.0 x 1.00 mm

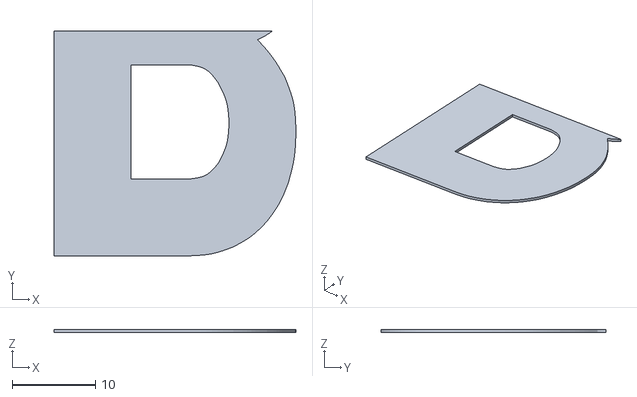
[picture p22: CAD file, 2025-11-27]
3dModels/Models/Flaps 1-9/Flap4_2.stl
29.0 x 26.9 x 0.4

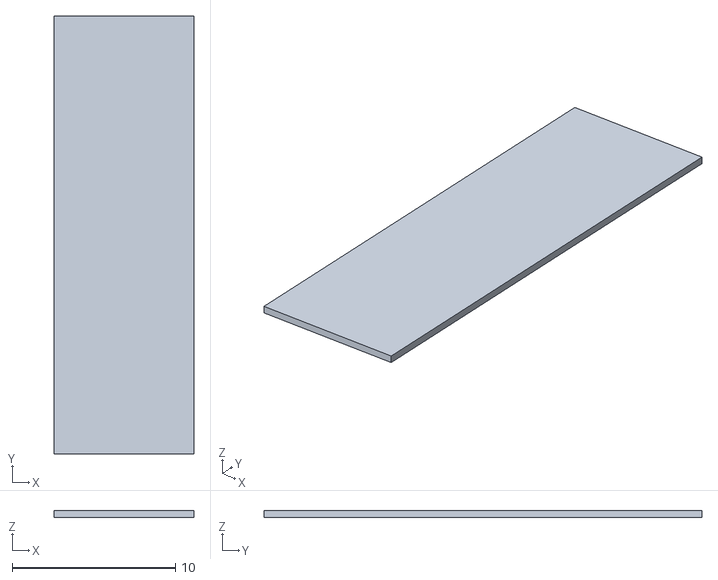
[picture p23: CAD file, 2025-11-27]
3dModels/Models/Flaps 10-18/Flap14_3.stl
8.58 x 26.8 x 0.4

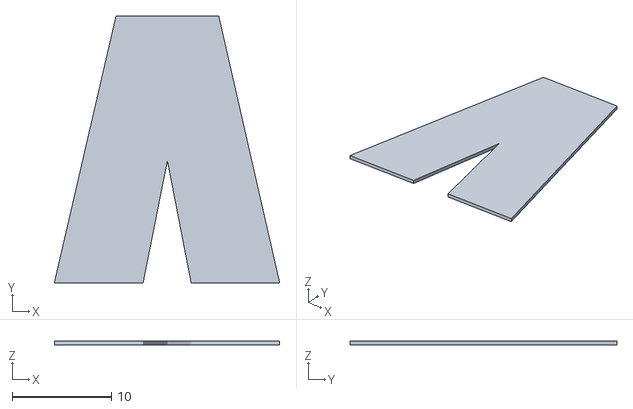
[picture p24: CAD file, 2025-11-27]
3dModels/Models/Flaps 19-27/Flap23_3.stl
22.7 x 26.9 x 0.4

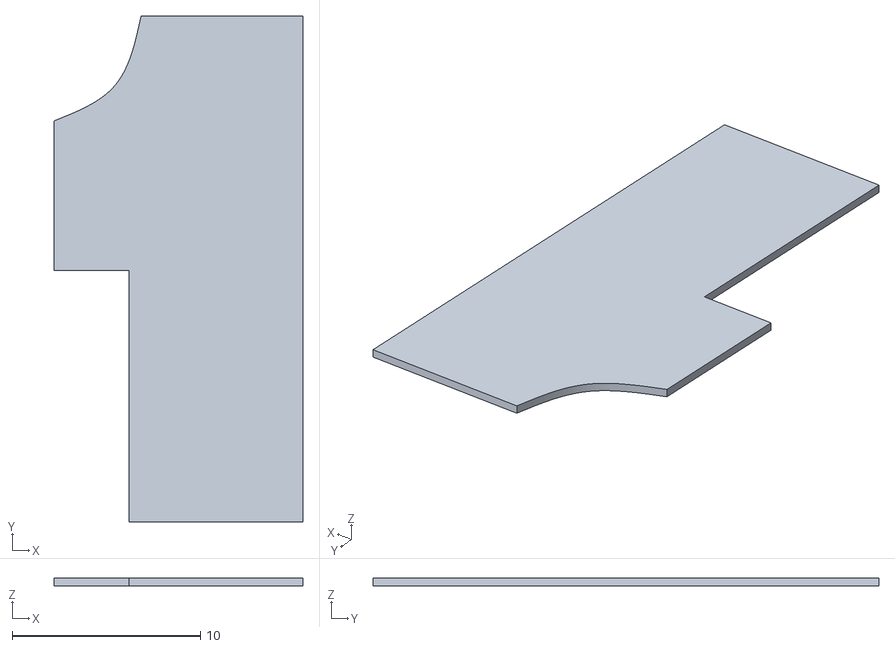
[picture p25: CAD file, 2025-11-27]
3dModels/Models/Flaps 28-36/Flap33_1.stl
13.2 x 26.9 x 0.4

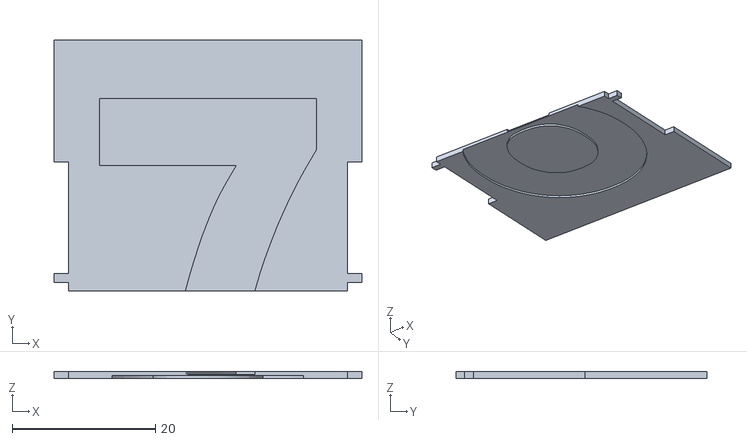
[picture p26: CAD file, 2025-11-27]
3dModels/Models/Flaps 37-45/Flap39.stl
43.0 x 35.0 x 1.00

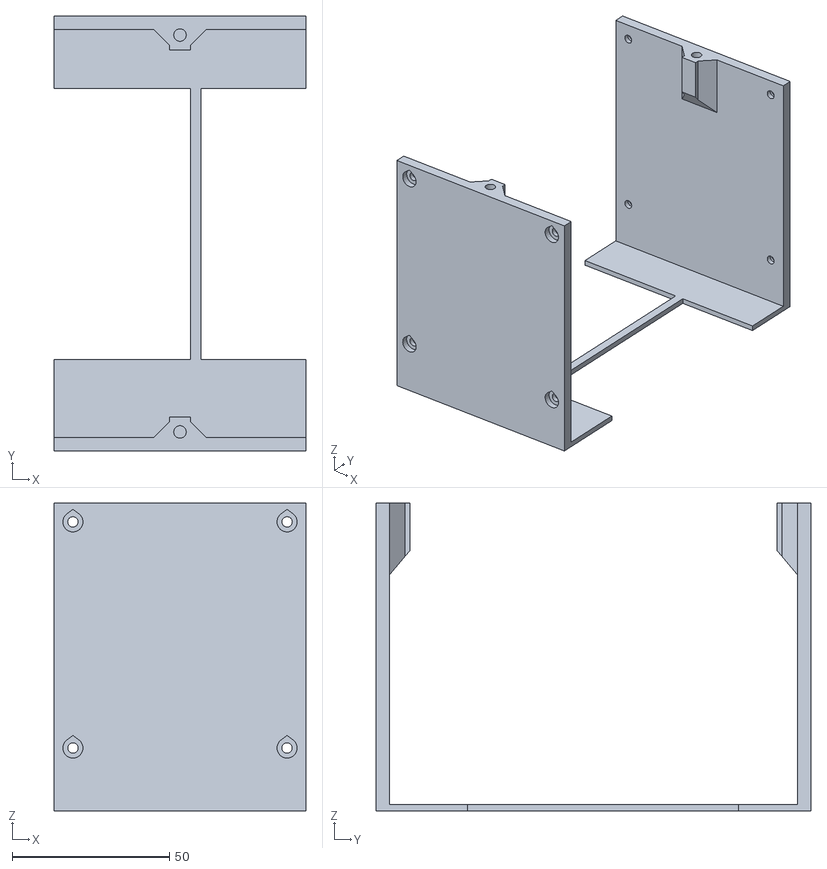
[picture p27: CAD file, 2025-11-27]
3dModels/Models/FrontCover/FrontCoverCenter.stl
80.0 x 138.0 x 97.8

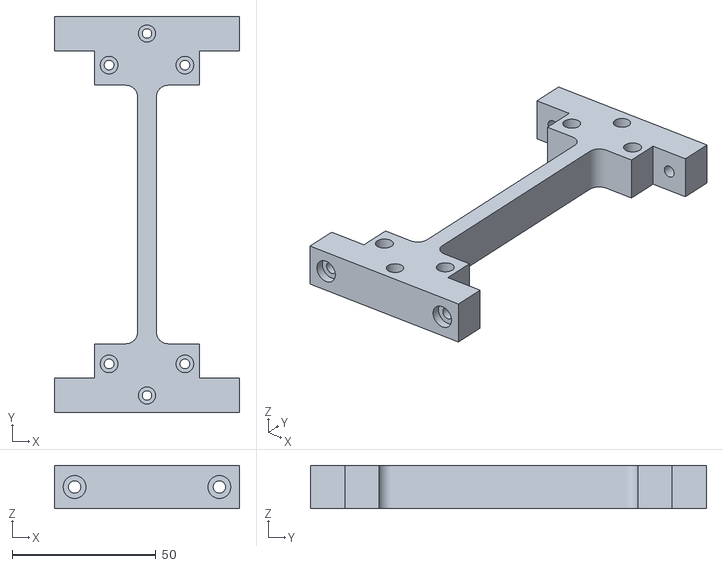
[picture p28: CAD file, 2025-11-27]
3dModels/Models/MiddleFrame/MiddleFrameCenter.stl
64.4 x 138.0 x 15.0

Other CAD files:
3dModels/Models/Unit/FlapDrumInner.stl
PCB/KiCad_Export/SplitFlap.step
3dModels/Models/BackCover/BackCoverLeft.stl
3dModels/Models/Flap 28-36 no umlaute/Flap29_1_no_um.stl
3dModels/Models/BackCover/BackCoverRight.stl
3dModels/Models/Flap 28-36 no umlaute/Flap28_1_no_um.stl
3dModels/Models/Flap 28-36 no umlaute/Flap28_2_no_um.stl
3dModels/Models/Flap 28-36 no umlaute/Flap28_no_um.stl
3dModels/Models/Flap 28-36 no umlaute/Flap29_2_no_um.stl
3dModels/Models/Flap 28-36 no umlaute/Flap29_no_um.stl
3dModels/Models/Flap 28-36 no umlaute/Flap30_1_no_um.stl
3dModels/Models/Flap 28-36 no umlaute/Flap30_2_no_um.stl
3dModels/Models/Flap 28-36 no umlaute/Flap30_no_um.stl
3dModels/Models/Flap 28-36 no umlaute/Flap31_1_no_um.stl
3dModels/Models/Flap 28-36 no umlaute/Flap31_2_no_um.stl
3dModels/Models/Flap 28-36 no umlaute/Flap31_no_um.stl
3dModels/Models/Flap_blank_do_not_print.stl
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

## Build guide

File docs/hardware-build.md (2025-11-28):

# Hardware Build Guide

This document walks through the mechanical and electrical assembly of the
split-flap display—from PCB soldering to final enclosure assembly. Follow the
sections in order for the smoothest build.

## 1. CAD Changes vs Original Design

This fork includes a few small but important mechanical tweaks to the original
CAD to improve assembly, alignment and robustness:

- **Drum**
  - Increased magnet hole diameter from **2.1 mm → 2.2 mm** for easier insertion
    of 2 mm magnets.
  - Added more material around the magnet cavity and shifted it slightly inward
    to better align the magnet with the hall sensor path and reduce cracking.
  - Added small through-hole indicators for the **first flap position** on the
    drum to make flap ordering more obvious during assembly.
  - Added a simple **drum removal feature**: an M3 screw + nut can be used as a
    jack to push the motor shaft out of the press-fit drum without damage.
- **Frame**
  - Corrected oversized PCB mounting holes so the screws clamp the board
    securely.
  - Widened the cable channel by ~1 mm to give wiring more space and reduce
    pinching when closing the case.

## 2. PCB Preparation

Use the Gerber files in `PCB/` and have one board fabricated per unit. Populate
*all* footprints for the first unit (it hosts the ESP-01S) and only the required
5 V circuitry for subsequent units.

### 1.1 Mandatory components (all units)

- ULN2003A Darlington driver (U4)
- L7805 5 V regulator (U3) plus its capacitors
- JST-XH motor, hall sensor and daisy-chain connectors
- Arduino Nano female headers
- DIP switch (SW1) for unit addressing

### 1.2 First unit extras

The first PCB also hosts the hub electronics:

- ESP-01S module + 3.3 V regulator (AMS1117-3.3)
- Level shifting (BSS138 + resistors) for I²C
- Pull-ups for SDA/SCL

Populate every component on the back side for unit #0. Subsequent boards only
need the 5 V path (leave 3.3 V parts unpopulated).

### 1.3 Assembly tips

- Install heat-set inserts before final soldering to avoid reheating populated
  boards.
- Keep the ESP-01S socket accessible; you will swap the module during firmware
  work.
- Double-check polarity on electrolytics and regulators.

## 3. Wiring & Cable Looms

Prepare wiring harnesses before mechanical assembly:

- **Daisy-chain cables:** 9 × cables with 4 × 70 mm wires (XH-4P on both ends)
- **Power lead:** one cable with XH-4P on one end, free leads to the rocker
  switch and DC jack on the other
- **Hall sensors:** 10 × sensors with 3 × 220 mm wires, terminated with XH-3Y

Label cables per unit to avoid confusion later.

## 4. Unit Assembly

Each unit consists of:

1. FrameUnit print with inserts installed
2. Stepper motor mounted using M3 hardware
3. Hall sensor positioned near the magnet path
4. PCB secured with screws; connect stepper + hall harnesses
5. Drum + flaps installed (see Section 4 of `printing.md`)

### Tips

- Press two M3 nuts diagonally into the frame back; use temporary screws to
  pull them tight.
- Route wiring through the provided channels (see legacy Figures 11–13).
- **Hall sensor mounting:** The hall sensor mounting holes in this version have
  **9 mm spacing** (prior versions used 10.9 mm spacing). Ensure your hall sensor
  PCB matches this spacing before mounting.
- Confirm the hall sensor LED only lights when a magnet is nearby.

## 5. Middle Frame & Case

### 4.1 MiddleFrame

1. Insert eight M3 heat-set inserts per the diagram.
2. Join Left, Center and Right pieces with the corresponding screws/nuts.
3. Mount each completed unit to the frame; daisy-chain the connectors as you go.

### 4.2 Front Cover

1. Insert six M3 heat-set inserts.
2. Bolt the three cover sections together.
3. Test-fit over the units to ensure cable clearance.

### 4.3 Back Cover

1. Join the three back sections.
2. Mount the rocker switch and DC socket, wiring them to the power harness.
3. Terminate with an XH-4Y plug to mate with the first unit.

## 6. Final Assembly Checklist

- [ ] All units securely mounted and wired in order (addresses 0…n-1)
- [ ] Hall sensors aligned; magnets glued with consistent polarity and marked
- [ ] Flaps rotate freely without rubbing
- [ ] Power path tested (12 V supply, polarity confirmed)
- [ ] ESP-01S sits firmly on the first PCB with antenna clearances
- [ ] Enclosure closes without pinching cables

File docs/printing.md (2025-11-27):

# Printing & Bill of Materials

This guide consolidates everything required to print, source and prepare the
mechanical parts of the split-flap display. Print and procurement planning up
front will save a lot of time during the hardware build.

## Filament & General Materials

Quantities below assume a 10-unit display (the PCB supports up to 16 units).

- **Black filament:** ~2.6 kg PLA (frame, covers, structural pieces)
- **White filament:** ~250 g PLA (cladding, accents)
- **Magnets:** 10 × 2 mm × 1 mm neodymium discs
- **Wire:** 22 AWG silicone (power), 26 AWG stranded (signal, two colours)
- **Switches & power:**
  - Rocker switch (panel mount)
  - DC barrel jack (<9 mm hole)
  - 12 V, ≥24 W PSU
- **Hall sensors:** 10 × KY-003 5 V momentary hall sensor modules
- **Stepper motors:** 10 × 28BYJ-48 **12 V** steppers (do not use 5 V variants)
- **Heat-set inserts:** 14 × M3, 20 × M2x3.6x4. If you are not using the referenced Ruthex hardware, match their dimensions (M2 inserts are 4 mm long × 3.6 mm
  diameter) so they grip properly in the printed parts.

> Tip: Links to example parts are in the legacy instructions and may change
> over time. Double-check dimensions before ordering.

## Screw & Insert Reference

| Screw / Insert | Total | UnitFrame | Stepper | HallSensor | PCB | FlapDrum | MiddleFrame | FrontCover | BackCover |
| --- | --- | --- | --- | --- | --- | --- | --- | --- | --- |
| M4 Nut | 4 | – | – | – | – | – | 4 | – | – |
| M3 Nut | 32 | – | – | – | – | – | 20 | 8 | 4 |
| M4×8 mm pan head | 20 | 20 | – | – | – | – | – | – | – |
| M4×20 mm pan head | 4 | – | – | – | – | – | 4 | – | – |
| M3×16 socket cap | 34 | – | – | – | – | – | 20 | 6 | 8 |
| M3×8 mm pan head | 12 | – | – | – | – | – | 8 | 4 | – |
| M3×6 mm | 20 | – | – | – | 20 | – | – | – | – |
| M2×8 mm pan head | 20 | – | – | – | 20 | – | – | – | – |
| M2×4 mm | 20 | – | – | – | 20 | – | – | – | – |
| M3 heat insert | 14 | – | – | – | – | – | 8 | 6 | – |
| M2 heat insert | 20 | – | – | – | 20 | – | – | – | – |

## PCB Bill of Materials

All passives are 0805 packages. You need one PCB per flap unit.

| ID | Item | Designators | Qty | LCSC / Notes |
| --- | --- | --- | --- | --- |
| 1 | ESP-01S | U2 | 1 | ESP-01S much better than ESP01 |
| 2 | 10 kΩ resistor | R1–R4 | 4 | LCSC C269742 |
| 3 | BSS138 MOSFET | Q1–Q2 | 2 | LCSC C78284 |
| 4 | 330 nF capacitor | C1 | 1 | LCSC C527609 |
| 5 | Arduino Nano | U1 | 1 | Use genuine or quality clone |
| 6 | 100 nF capacitor | C2 | 1 | LCSC C521242 |
| 7 | AMS1117-3.3 | U9 | 1 | LCSC C6186 |
| 8 | JST-XH-5A | U10 | 1 | LCSC C161872 |
| 9 | L7805CV regulator | U3 | 1 | LCSC C111887 |
| 10 | ULN2003A | U4 | 1 | LCSC C107221 |
| 11 | 22 µF capacitor | C5 | 1 | LCSC C503893 |
| 12 | JST-XH-3A | U6 | 1 | LCSC C144394 |
| 13 | JST-XH-4A | U7–U8 | 2 | LCSC C161871 |
| 14 | DSWB04LHGET DIP switch | SW1 | 1 | LCSC C964138 |

Get an assortment of JST-XH housings and the matching crimp tool:

- 10 × XH-3A
- 20 × XH-4A
- 10 × XH-5A
- 10 × XH-3Y
- 19 × XH-4Y

Single-row female headers (2.54 mm pitch) are also required:

- 20 × 15-pin strips
- 1 × 4-pin, 2-row header

## Printed Parts Manifest

Download the latest `.3mf` or STL bundle from Printables:
https://www.prusaprinters.org/prints/69464-split-flap-display

Print the following:

- 10 × FlapDrumInner + FlapDrumOuter
- 10 × FrameUnit
- 1 × MiddleFrameLeft / Center / Right
- 1 × FrontCoverLeft / Center / Right
- 1 × BackCoverLeft / Center / Right

## Flap Printing

Flaps are the trickiest part—test a few before committing to all 45 × units.

- Each flap is 1 mm thick; font is *Expressway Condensed Bold*.
- Colour changes happen mid-layer via `M600` commands in the provided `.3mf`
  files.
- Need 10 copies of every flap (two-sided).

**Character sets**

- *Standard set:* `␠ A–Z Ä Ö Ü 0–9 : . - ? !`
- *Noum set (no Umlauts):* `␠ A–Z $ & # 0–9 : . - ? !`

> Pro tip: Open the generated G-code and remove the first `M600` line to avoid a
> filament change at print start.

## Power Consumption Reference

- 13 mA @ 12 V (0.15 W) per unit when idle
- 186 mA @ 12 V (2.22 W) per unit while flipping
- 90 mA @ 12 V (1.08 W) for the ESP-01S hub
- Full 10-unit build with ESP-01S: 220 mA idle / 1.73 A active at 12 V

Plan your PSU accordingly (≥25 W recommended).

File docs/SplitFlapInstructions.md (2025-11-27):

# Split-Flap Building Instructions

**Author:** David Königsmann  
**Date:** April 29, 2022

---

## Table of Contents

1. [Introduction](#1-introduction)
2. [Hardware](#2-hardware)
   - 2.1 [General electronics](#21-general-electronics)
   - 2.2 [Screws](#22-screws)
   - 2.3 [Power Consumption](#23-power-consumption)
3. [PCBs](#3-pcbs)
   - 3.1 [Bill of Materials](#31-bill-of-materials)
   - 3.2 [Schematic](#32-schematic)
   - 3.3 [Soldering PCBs](#33-soldering-pcbs)
     - 3.3.1 [First unit](#331-first-unit)
     - 3.3.2 [All other units](#332-all-other-units)
4. [Printed parts](#4-printed-parts)
   - 4.1 [Flaps](#41-flaps)
5. [Assembly](#5-assembly)
   - 5.1 [Drum and Flaps](#51-drum-and-flaps)
   - 5.2 [Units](#52-units)
     - 5.2.1 [Cables](#521-cables)
     - 5.2.2 [Unit Assembly](#522-unit-assembly)
   - 5.3 [Case](#53-case)
     - 5.3.1 [MiddleFrame](#531-middleframe)
     - 5.3.2 [FrontCover](#532-frontcover)
     - 5.3.3 [BackCover](#533-backcover)
6. [Code](#6-code)

---

**Support the project:** If you would like to support my projects and help me buy more electronics:  
https://www.paypal.me/davidkoenigsmann

---

## 1 Introduction

Welcome to the documentation of my split-flap display.

This split-flap display sets itself apart by being almost completely 3D-printed. The flaps are printed by changing the color mid-print and mid-layer. The case is also completely 3D-printed.

If you really want to build one consider that it requires a lot of screws, heat-set inserts, many hours of printing and some electronics. The PCB also has a few SMD parts. Smallest component size is 0805. Some soldering experience is necessary. **Please try printing the flaps first, they are the most challenging to print.**

### General info about display:

- 10 units (PCB design allows up to 16)
- 45 flaps per unit
- Size: 513 mm x 136 mm x 138 mm

**3D-Files on Prusaprinters:** https://www.prusaprinters.org/prints/69464-split-flap-display  
**Github link to code:** https://github.com/Dave19171/split-flap

---

## 2 Hardware

### 2.1 General electronics

All quantities are for the 10-unit display. Amazon/Ebay/Aliexpress URLs are just examples and are interchangeable with similar products. I can not guarantee that the URLs point to the correct product. Please double check.

- Black filament, I used around 2.6 kg of PLA
- White filament, I used around 250 Grams of PLA
- **10 of 12V 28BYJ-48 stepper motor** - **IMPORTANT! ONLY 12V STEPPERS WILL WORK!**
- 10 of KY-003 5V momentary (not the latching ones) hall sensor with PCB  
  https://www.aliexpress.com/item/32661635775.html
- 10 of 2x1 mm disk neodymium magnet  
  https://www.ebay.de/itm/184668664439?var=692394581260
- 14 of M3 heat-set threaded insert  
  https://www.amazon.de/gp/product/B08BCRZZS3/
- 20 of M2 heat-set threaded insert  
  https://www.amazon.de/gp/product/B088QJG676/
- 22 AWG silicone wire  
  https://www.amazon.de/gp/product/B07W5ZMBYL/
- 26 AWG stranded wire, two colors
- 1 rocker switch  
  https://www.amazon.de/dp/B076GXD7XN/
- 1 DC socket for <9 mm hole size
- 1 12V >24 Watts power supply
- For PCB components see PCB section

### 2.2 Screws

This display requires a lot of different screws. I made a table to quickly see where the screw types go and how many you need.

| Screw Type | UnitFrame | Stepper | HallSensor | PCB | FlapDrum | MiddleFrame | FrontCover | BackCover | Total |
|---|---|---|---|-----|---|---|---|---|---|
| M4 Nut | | | | | | 4 | | | 4 |
| M3 Nut | | | | | | 20 | 8 | 4 | 32 |
| M4x8 mm Panhead | 20 | | | | | | | | 20 |
| M4x20 mm Panhead | | | | | | 4 | | | 4 |
| M3x16 Socket Cap Hex | | | | | | 20 | 6 | 8 | 34 |
| M3x8 Panhead | | | | | | 8 | 4 | | 12 |
| M3x6 mm | | | | 20 | | | | | 20 |
| M2x8 mm Panhead | | | | 20 | | | | | 20 |
| M2x4 mm | | | | 20 | | | | | 20 |
| M3 Heat Insert | | | | | | 8 | 6 | | 14 |
| M2 Heat Insert | | | | 20 | | | | | 20 |

**Table 1:** Screw sizes, quantity and assignment to part group

### 2.3 Power Consumption

I desoldered the power LED on the Arduinos to save more power.

#### Here are the stats on power consumption per Unit:

- 13 mA at 12V = 0.15 Watt per Unit when idle
- 186 mA at 12V = 2.22 Watts per Unit when actively flipping
- 90 mA at 12V = 1.08 Watt for the ESP01 (always on)

#### For a 10-Unit display including the ESP01:

- 220 mA at 12V = 2.63 Watts when idle
- 1.73 A at 12V = 20.76 Watts with all units flipping at the same time

---

## 3 PCBs

Use the gerber files from github and get 10 PCBs manufactured.

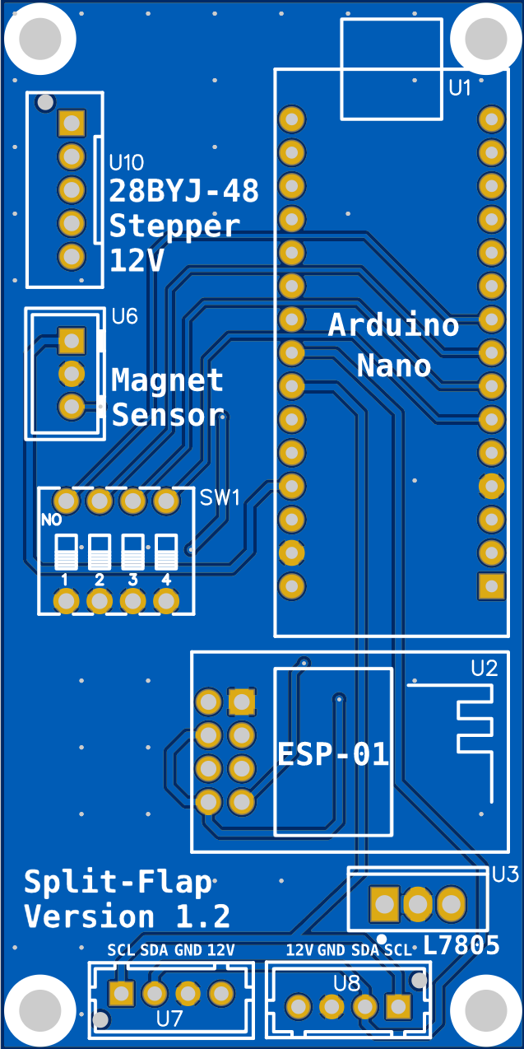
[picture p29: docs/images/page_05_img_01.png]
Split-Flap PCBs front and back side


**Figure 1:** Split-Flap PCBs front and back side

### 3.1 Bill of Materials

- Get an assortment of JST-XH connectors and the correct crimping tool, you need:
  - 10x XH-3A
  - 20x XH-4A
  - 10x XH-5A
  - 10x XH-3Y
  - 19x XH-4Y  
  https://www.amazon.de/gp/product/B07VW8F1NB/
- Either get a bunch of single row female headers with 2.54 mm pitch and cut them to length or get the following lengths:
  - 20 x 15 Pins 1 Row
  - 1 x 4 Pins 2 Rows

All resistors and capacitors are 0805 size.

| ID | Name | Designator | Quantity | LCSC Number | Total |
|----|---|---|---|---|---|
| 1 | ESP-01 | U2 | 1 | | 1 |
| 2 | 10K Resistor | R1,R2,R3,R4 | 4 | C269742 | 4 |
| 3 | BSS138 | Q1,Q2 | 2 | C78284 | 2 |
| 4 | 330nF | C1 | 1 | C527609 | 10 |
| 5 | Arduino Nano | U1 | 1 | | 10 |
| 6 | 100nF | C2 | 1 | C521242 | 10 |
| 7 | AMS1117-3.3 | U9 | 1 | C6186 | 1 |
| 8 | JST-XH-5A | U10 | 1 | C161872 | 10 |
| 9 | L7805CV | U3 | 1 | C111887 | 10 |
| 10 | ULN2003A | U4 | 1 | C107221 | 10 |
| 11 | 22 µF | C5 | 1 | C503893 | 1 |
| 12 | JST-XH-3A | U6 | 1 | C144394 | 10 |
| 13 | JST-XH-4A | U7,U8 | 2 | C161871 | 20 |
| 14 | DSWB04LHGET | Sw1 | 1 | C964138 | 10 |

**Table 2:** Bill of Materials

### 3.2 Schematic

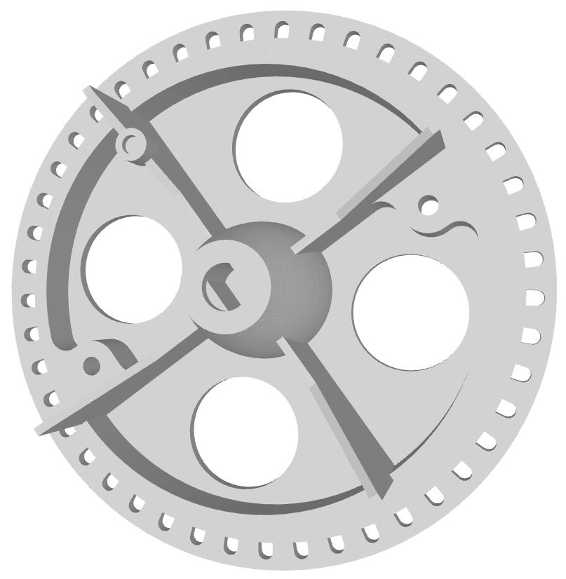
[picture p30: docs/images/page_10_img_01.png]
PCB Schematic


**Figure 2:** PCB Schematic

### 3.3 Soldering PCBs

Every PCB needs the ULN2003A, the L7805 5V regulator, JST-XH sockets, female row headers for the Arduino and the DIP switch.

#### 3.3.1 First unit

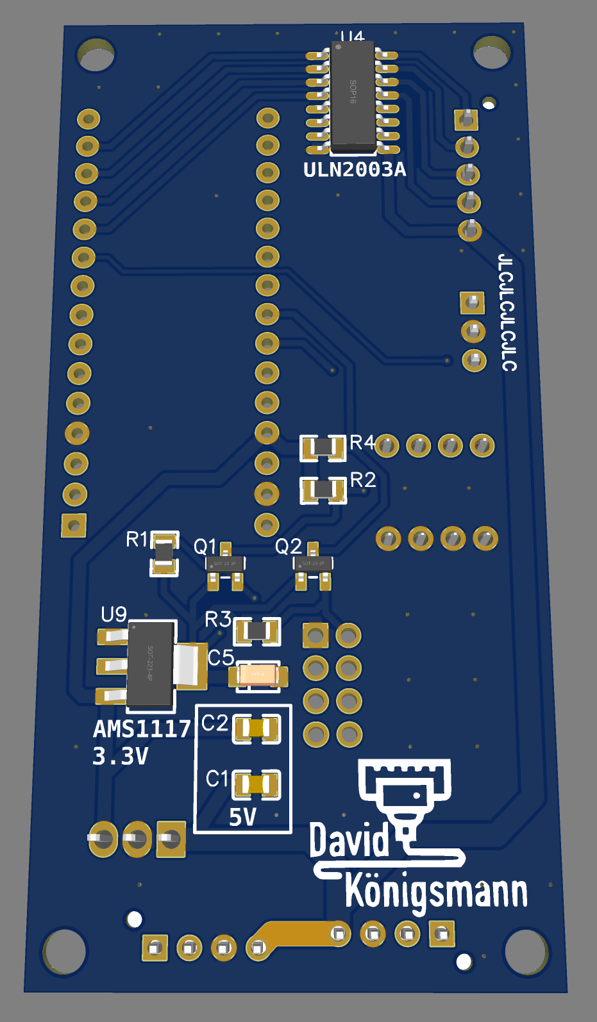
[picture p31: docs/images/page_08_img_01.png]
PCB back side with all components for first unit


**Figure 3:** PCB back side with all components for first unit

The first unit has the ESP-01 and therefore needs a 3.3V regulator, level shifter and pull-up resistors for I2C communication. Populate the back side of the first unit with every component.

#### 3.3.2 All other units

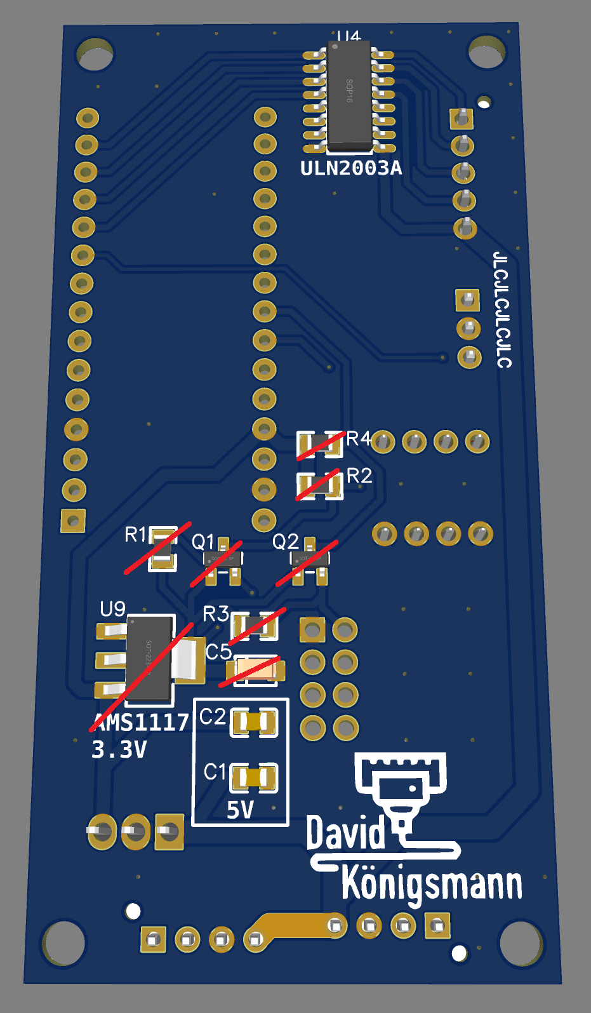
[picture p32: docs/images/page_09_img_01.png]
PCB back and front side with components for second unit onward


**Figure 4:** PCB back and front side with components for second unit onward

All other units do not need 3.3V. Just solder the two capacitors for the 5V circuit indicated by the silkscreen.

---

## 4 Printed parts

**3D-Files on Prusaprinters:**  
https://www.prusaprinters.org/prints/69464-split-flap-display

**Required printed parts:**

- 10 x FlapDrumInner
- 10 x FlapDrumOuter
- 10 x FrameUnit
- 1 x MiddleFrameLeft
- 1 x MiddleFrameCenter
- 1 x MiddleFrameRight
- 1 x FrontCoverLeft
- 1 x FrontCoverCenter
- 1 x FrontCoverRight
- 1 x BackCoverLeft
- 1 x BackCoverCenter
- 1 x BackCoverRight

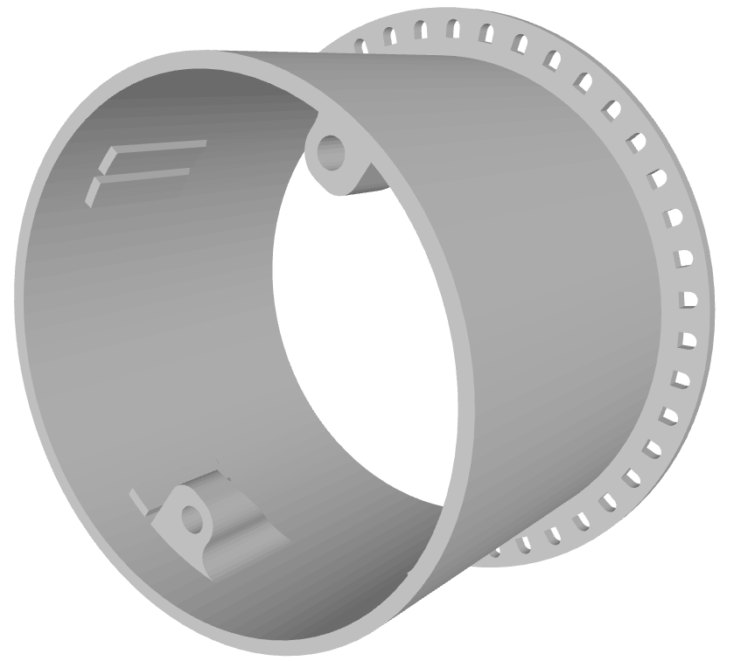
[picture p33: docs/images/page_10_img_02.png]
Overview printed parts


**Figure 5:** Overview printed parts

For the cover and frame parts I recommend a 0.6 mm nozzle and >0.3 mm layers. The bigger layer height accelerates printing and provides more strength. Maybe use a brim.

### 4.1 Flaps

**Try printing a few flaps first! These are the most challenging to print.**

The flaps are printed by changing the color several times mid-print. I provided .3mf files for easy printing on Prusa machines or if you are using PrusaSlicer. Print 10 of each flap.

If you do not need the Umlauts (ÄÖÜ) you can print the flaps with "noum" at the end of their name instead. This way you get the following three symbols: $ & #

**Pro tip:** If you open the resulting gcode with a text editor and delete the first M600 instruction, you don't have to change filaments every time the print starts.

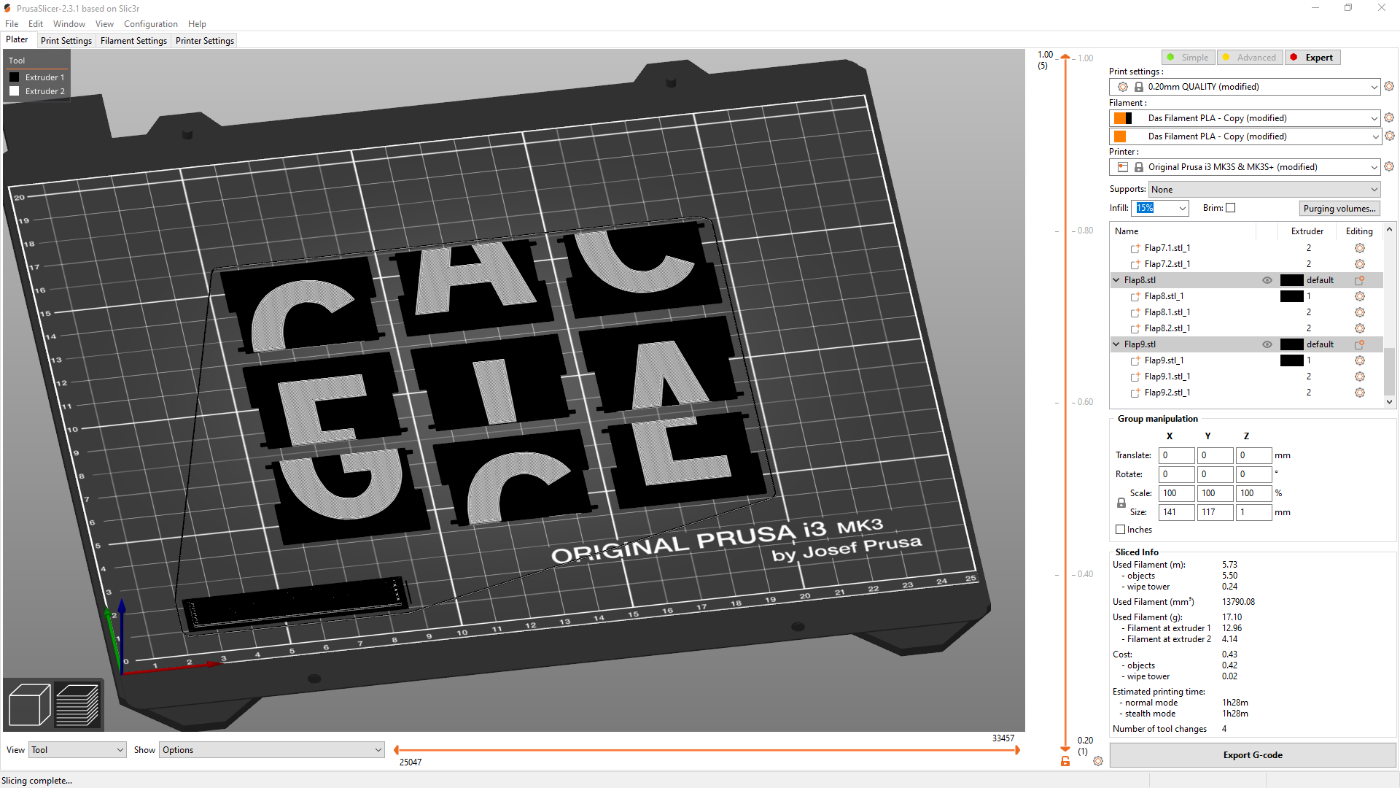
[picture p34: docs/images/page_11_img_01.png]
Flaps in PrusaSlicer


**Figure 6:** Flaps in PrusaSlicer

In case you want to make the flaps some other way, here are the measurements. Thickness is 1 mm. Font is Expressway Condensed Bold.

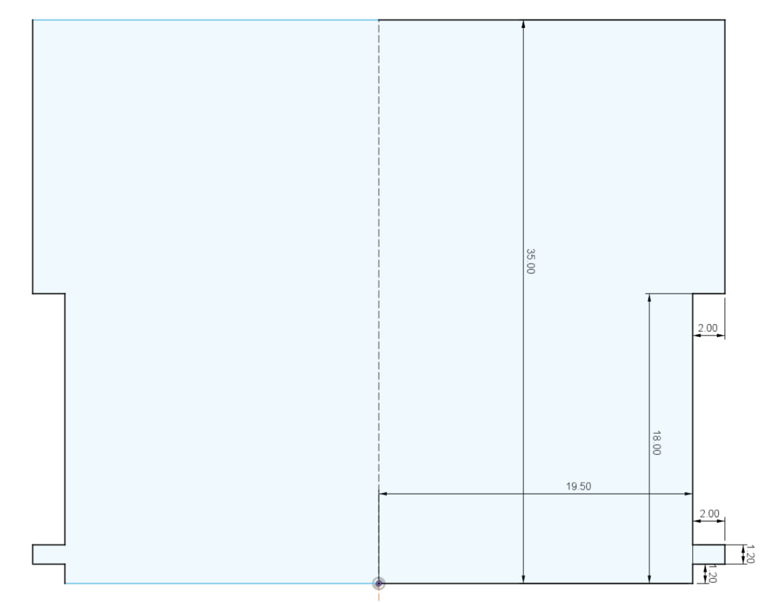
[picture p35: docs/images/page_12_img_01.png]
Flap measurements in millimeters


**Figure 7:** Flap measurements in millimeters

**Flap order:**

With Umlauts: ' ', 'A', 'B', 'C', 'D', 'E', 'F', 'G', 'H', 'I', 'J', 'K', 'L', 'M', 'N', 'O', 'P', 'Q', 'R', 'S', 'T', 'U', 'V', 'W', 'X', 'Y', 'Z', 'Ä', 'Ö', 'Ü', '0', '1', '2', '3', '4', '5', '6', '7', '8', '9', ':', '.', '-', '?', '!'

Or if you are using the alternative "noum" flaps: ' ', 'A', 'B', 'C', 'D', 'E', 'F', 'G', 'H', 'I', 'J', 'K', 'L', 'M', 'N', 'O', 'P', 'Q', 'R', 'S', 'T', 'U', 'V', 'W', 'X', 'Y', 'Z', '$', '&', '#', '0', '1', '2', '3', '4', '5', '6', '7', '8', '9', ':', '.', '-', '?', '!'

---

## 5 Assembly

### 5.1 Drum and Flaps

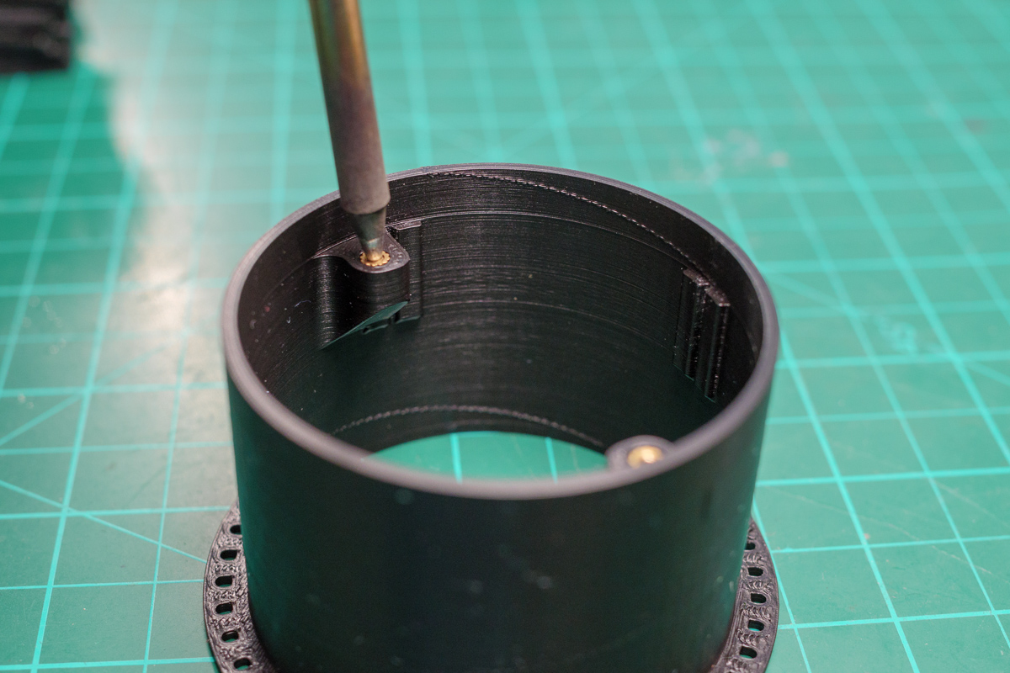
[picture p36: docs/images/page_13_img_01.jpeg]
Drum Insert Installation


**Figure 8:** Drum Insert Installation

Press two drum pieces together. It is a friction fit, a bit of force may be required. After that, the two halves should stay together but can also be separated. Heat up your soldering iron to 200 °C and press the two inserts in.

Before you glue the magnet you have to figure out which way it is supposed to go. Supply one of the hall sensors with 5V and test to which side the little red LED reacts. If it turns on you have found the correct orientation. It is good practice to mark the correct pole of the magnet with a permanent marker. Then glue the magnets in the hole of the FlapDrumInner part.

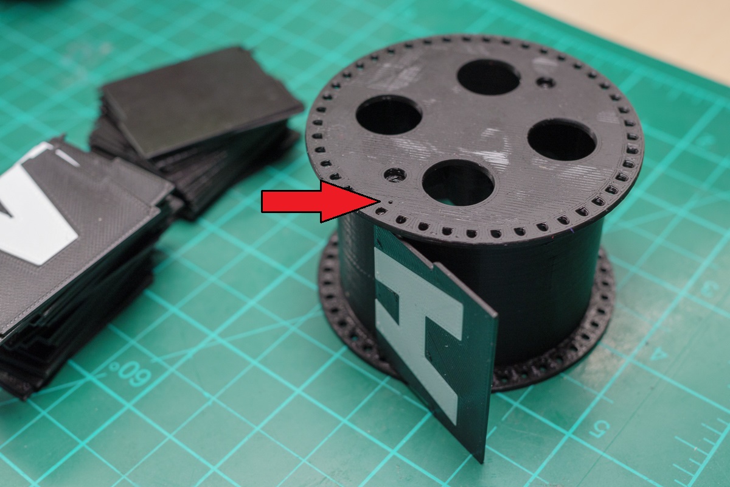
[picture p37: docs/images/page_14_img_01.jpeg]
Flap Installation


**Figure 9:** Flap Installation

Now you can install the flaps. Take a closer look at the two drum parts. On each side there is a small circle on the bottom that indicates the position of the first flap. These should be aligned on both pieces. The first flap is the one which is blank on one side and has the bottom of the A on the other. Lift the outer drum part a bit, insert some flaps, press it together again and repeat.

Secure the drum with two screws.

### 5.2 Units

#### 5.2.1 Cables

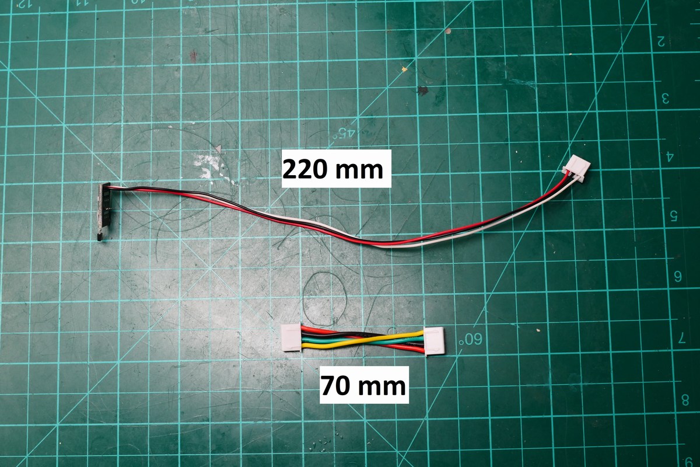
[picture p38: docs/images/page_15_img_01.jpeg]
Cable lengths


**Figure 10:** Cable lengths

- Prepare 9 cables with 4 x 70 mm wires each and XH-4P plugs on both sides
- Prepare one cable with just one plug and two power wires and connect them to the switch and DC socket
- Solder 3 x 220 mm wires to the hall sensor PCB and crimp a XH-3Y plug on the end

#### 5.2.2 Unit Assembly

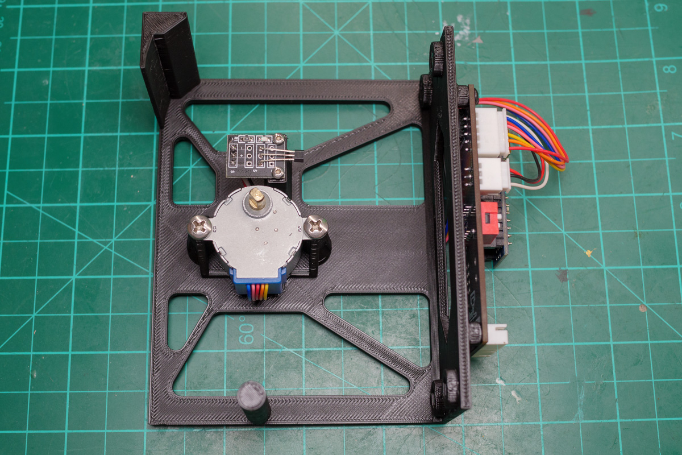
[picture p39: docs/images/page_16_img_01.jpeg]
FrameUnit Top View


**Figure 11:** FrameUnit Top View

Push two M3 nuts diagonally in the back of the frame. Use a screw to pull the nut if necessary.

Mount the hall sensor and stepper.

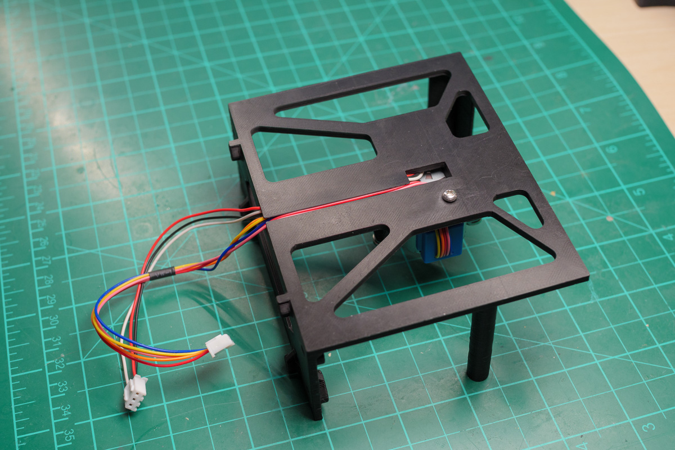
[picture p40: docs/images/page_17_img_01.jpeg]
FrameUnit Cable Management


**Figure 12:** FrameUnit Cable Management

Route the cables through the back and push them in the channel.

Mount the PCB with two screws and plug in the hall sensor and stepper.

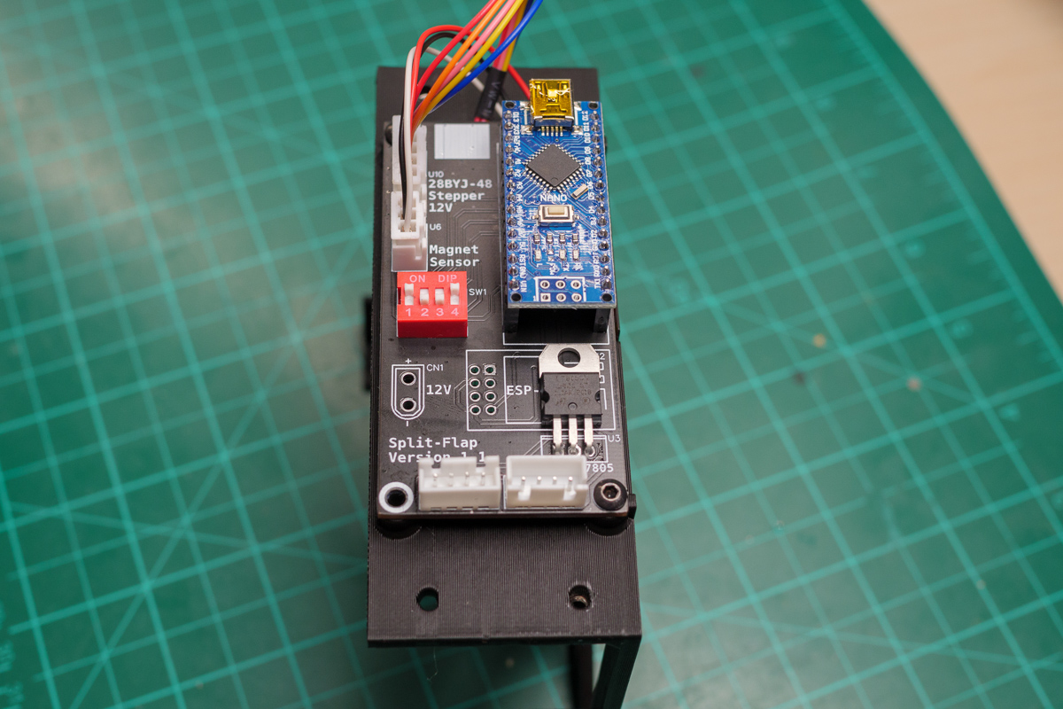
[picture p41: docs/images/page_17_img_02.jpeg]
FrameUnit Back Side


**Figure 13:** FrameUnit Back Side

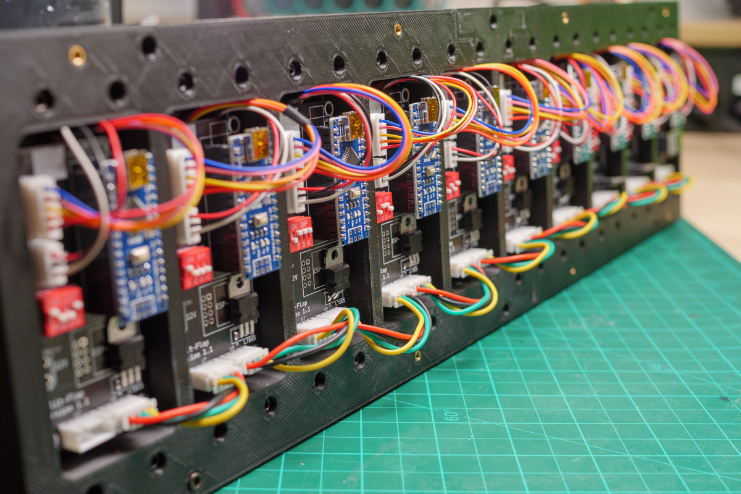
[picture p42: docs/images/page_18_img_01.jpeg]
Units mounted to MiddleFrame


**Figure 14:** Units mounted to MiddleFrame

Repeat this for all units.

### 5.3 Case

#### 5.3.1 MiddleFrame

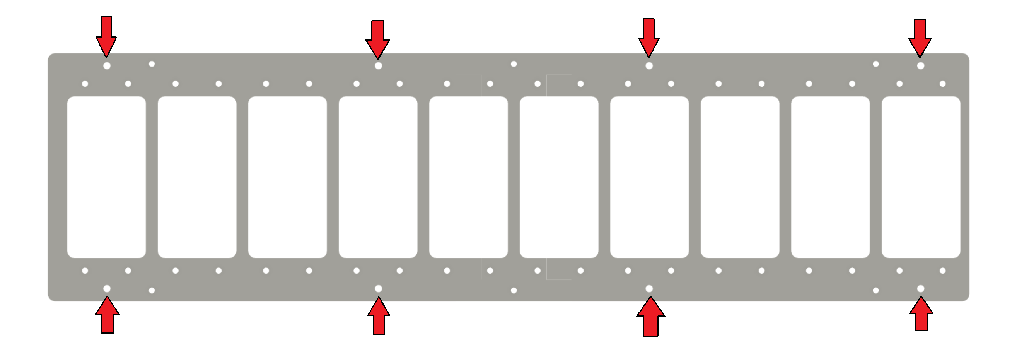
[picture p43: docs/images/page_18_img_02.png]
Insert position on MiddleFrame pieces


**Figure 15:** Insert position on MiddleFrame pieces

Insert eight M3 inserts as indicated in the picture with your soldering iron and connect the 3 pieces with the correct screw and nut.

#### 5.3.2 FrontCover

Insert six M3 inserts with your soldering iron and connect the 3 pieces with the correct screw and nut.

#### 5.3.3 BackCover

Connect the 3 pieces with the correct screw and nut. Insert the power switch and DC socket into their holes and connect them to a XH-4Y plug.

---

## 6 Code

**Github link to code and tutorial how to set everything up:**  
https://github.com/Dave19171/split-flap

---

*End of Instructions*

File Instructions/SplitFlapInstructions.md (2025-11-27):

# Split-Flap Building Instructions

**Author:** David Königsmann  
**Date:** April 29, 2022

---

## Table of Contents

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

---

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

---

## 1 Introduction

Welcome to the documentation of my split-flap display.

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

### General info about display:

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

i**3D-Files on Printables:** https://www.prusaprinters.org/prints/69464-split-flap-display  
**Github link to original code:** https://github.com/Dave19171/split-flap
**Github link to latest code, based on ....  

---

## 2 Hardware

### 2.1 General electronics

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

### 2.2 Screws

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

**Table 1:** Screw sizes, quantity and assignment to part group

### 2.3 Power Consumption

I desoldered the power LED on the Arduinos to save more power.

#### Here are the stats on power consumption per Unit:

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

#### For a 10-Unit display including the ESP01:

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

---

## 3 PCBs

Use the gerber files from github and get 10 PCBs manufactured.

**Figure 1:** Split-Flap PCBs front and back side

### 3.1 Bill of Materials

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

All resistors and capacitors are 0805 size.

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

**Table 2:** Bill of Materials

### 3.2 Schematic

**Figure 2:** PCB Schematic

*(Note: The schematic diagram would be best viewed in the original PDF or in the PCB design files)*

### 3.3 Soldering PCBs

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

#### 3.3.1 First unit

**Figure 3:** PCB back side with all components for first unit

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

#### 3.3.2 All other units

**Figure 4:** PCB back and front side with components for second unit onward

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

---

## 4 Printed parts

**3D-Files on Prusaprinters:**  
https://www.prusaprinters.org/prints/69464-split-flap-display

**Required printed parts:**

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

**Figure 5:** Overview printed parts

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

### 4.1 Flaps

**Try printing a few flaps first! These are the most challenging to print.**

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

**Figure 6:** Flaps in PrusaSlicer

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

**Figure 7:** Flap measurements in millimeters

**Flap order:**

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

---

## 5 Assembly

### 5.1 Drum and Flaps

**Figure 8:** Drum Insert Installation

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

**Figure 9:** Flap Installation

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

Secure the drum with two screws.

### 5.2 Units

#### 5.2.1 Cables

**Figure 10:** Cable lengths

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

#### 5.2.2 Unit Assembly

**Figure 11:** FrameUnit Top View

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

Mount the hall sensor and stepper.

**Figure 12:** FrameUnit Cable Management

Route the cables through the back and push them in the channel.

Mount the PCB with two screws and plug in the hall sensor and stepper.

**Figure 13:** FrameUnit Back Side

**Figure 14:** Units mounted to MiddleFrame

Repeat this for all units.

### 5.3 Case

#### 5.3.1 MiddleFrame

**Figure 15:** Insert position on MiddleFrame pieces

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

#### 5.3.2 FrontCover

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

#### 5.3.3 BackCover

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

---

## 6 Code

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

---

*End of Instructions*

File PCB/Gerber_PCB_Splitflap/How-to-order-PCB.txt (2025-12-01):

How to Order PCB

Please refer to:
https://docs.easyeda.com/en/PCB/Order-PCB

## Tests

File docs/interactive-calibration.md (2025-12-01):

# Interactive Calibration Tool

The Interactive Calibration tool (`InteractiveCalibration/InteractiveCalibration.ino`) is an improved alternative to the basic `EEPROM_Write_Offset.ino` utility. It guides you through a step-by-step calibration process to find the optimal offset value for each unit.

## Overview

This tool automatically:
- Homes the unit to find the zero position (magnet/Hall sensor)
- Guides you through measuring 5 flap positions
- Calculates the optimal offset using statistical methods
- Writes the offset to EEPROM automatically

The offset calculation uses the formula: **O + D/2**, where:
- **O** = Distance from home (zero point) to where the blank/space flap flips
- **D** = Average steps per flap (distance between consecutive flaps)
- **D/2** = Half the steps per flap (to center in the middle of the blank flap)

## Prerequisites

- **Important:** Disconnect the unit from all other units and the I2C bus. Only connect power and the USB serial cable. Serial communication can be unreliable when multiple units are connected due to power draw, I2C bus interference, or electrical noise.
- Arduino Nano with Unit.ino firmware (or fresh Arduino)
- USB cable for serial communication
- Serial Monitor access

## Setup

1. **Open the sketch:**
   - Navigate to `InteractiveCalibration/InteractiveCalibration.ino` in Arduino IDE
   - This is a standalone sketch (not in the same folder as `EEPROM_Write_Offset.ino`)

2. **Upload the firmware:**
   - Select *Arduino Nano* board (use *ATmega328P (Old Bootloader)* if uploads fail)
   - Select the correct COM port
   - Upload the sketch

3. **Open Serial Monitor:**
   - Set baud rate to **9600**
   - Set line ending to **"Newline"** or **"Both NL & CR"**
   - **Note:** You may need to press the reset button on the Arduino after upload for serial output to work correctly

## Usage

### Step 1: Initial Setup

After upload and reset, you should see:
```
init
========================================
Interactive Flap Calibration Tool
Firmware Version: 1.0.7
========================================

Steps per flap (calculated): 45.29

Initializing stepper motor...
Starting homing sequence...
```

The unit will automatically home itself (find the magnet/Hall sensor position).

### Step 2: First Measurement

After homing completes, you'll see:
```
>>> What letter do you see? (type letter and press Enter):
```

**Type the letter you see** (e.g., `!`, `A`, `?`, etc.) and press Enter. This tells the tool which flap the unit is currently at.

**Important:** The first measurement can be at any flap - the tool will calculate the offset correctly regardless of where you start.

### Step 3: Subsequent Measurements

After the first measurement, the tool will:
1. Move slowly to the next letter
2. Display: `Moving slowly - press Enter IMMEDIATELY when the next letter flips!`
3. Continue moving very slowly (one step every 100ms)
4. **Press Enter as soon as you see the next letter flip**

The tool will automatically:
- Record the position
- Move to the next letter
- Repeat until 5 measurements are complete

### Step 4: Automatic Completion

After 5 measurements, the tool will:
- Calculate the optimal offset
- Filter out outliers
- Display detailed statistics
- Write the offset to EEPROM
- Show confirmation: `Value written to EEPROM: XX`

### Early Exit

You can type `Q` and press Enter at any time to finish early (after at least 3 measurements).

## How It Works

### Offset Calculation

The tool uses a two-part calculation:

1. **O (Offset to blank flap):**
   - Calculates the distance from home (zero point) to where the blank/space flap (index 0) flips
   - Accounts for which flap you started on
   - Always calculates forward distance (wrapping around if needed) to ensure positive offset

2. **D (Steps per flap):**
   - Measures the distance between consecutive flap flips
   - Uses median and filters outliers (more than 20 steps from median)
   - Averages the valid measurements

3. **Final offset = O + D/2:**
   - Centers the unit in the middle of the blank flap range
   - This is what `Unit.ino` expects when it applies the offset after finding the magnet

### Outlier Filtering

The tool filters outliers to improve accuracy:
- **Step differences:** Filters measurements more than 20 steps from the median
- **First measurement:** Always used (never filtered) since it establishes the starting point
- **Result:** Only truly bad measurements are excluded

### Example Calculation

If you start at "!" (index 44) and measure:
- Measurement 1: "!" at position 0 steps
- Measurement 2: " " (blank) at position 50 steps
- Measurement 3: "A" at position 95 steps
- Measurement 4: "B" at position 140 steps
- Measurement 5: "C" at position 185 steps

Calculation:
- **D** (steps per flap) = Average of (50-0, 95-50, 140-95, 185-140) = 45 steps
- **O** (to blank flap) = 0 + (1 flap × 45 steps) = 45 steps (from "!" to " ")
- **Final offset** = 45 + (45/2) = 45 + 22 = **67 steps**

## Troubleshooting

### Serial Output is Garbled

- Close Serial Monitor completely
- Upload the code again
- Wait 2-3 seconds after upload
- Open Serial Monitor at 9600 baud
- Press the reset button on the Arduino if needed

### Unit Doesn't Home

- Check Hall sensor wiring (pin 7)
- Verify magnet is properly aligned
- Check that Hall sensor LED lights up when near magnet
- Ensure motor can rotate freely (not physically stuck)

### Can't Press Enter in Time

- The tool moves very slowly (100ms per step)
- It continues moving until you press Enter
- You don't need to time it exactly - just press Enter when you see the letter flip
- If you miss it, the tool will timeout after 2× the slow region

### Offset Seems Wrong

- Make sure you're pressing Enter at the exact moment the letter flips
- Try running calibration again - the first 2 measurements are often less accurate
- Check that all 5 measurements were used (not filtered as outliers)
- Verify the calculated steps per flap is reasonable (~45 steps)

### "Q" Doesn't Work

- Make sure line ending is set to "Newline" in Serial Monitor
- Type "Q" and press Enter (not just Enter)
- You need at least 3 measurements before it will finish

## After Calibration

1. **Verify the offset:**
   - The tool displays: `Value written to EEPROM: XX`
   - Note this value for reference

2. **Upload Unit.ino:**
   - The offset is now saved in EEPROM
   - Upload `Unit/Unit.ino` firmware normally
   - The unit will use the saved offset automatically

3. **Test the unit:**
   - Connect to ESPMaster
   - Send a message via web UI
   - Verify the blank/space character displays correctly

## Comparison with EEPROM_Write_Offset.ino

| Feature | EEPROM_Write_Offset | Interactive Calibration |
|---|---|---|
| Manual entry | Yes, type offset value | No, measures automatically |
| User guidance | Minimal | Step-by-step instructions |
| Measurements | Single value | 5 measurements, filtered |
| Outlier handling | None | Automatic filtering |
| Accuracy | Depends on user | More accurate (averaged) |
| Time required | Fast (if you know offset) | ~5-10 minutes |
| Best for | Quick adjustments | Initial calibration |

## Technical Details

- **Baud rate:** 9600
- **Measurements:** 5 total (automatically stops)
- **Outlier threshold:** 20 steps from median
- **Slow movement speed:** 1 step per 100ms (~10 steps/second)
- **EEPROM address:** 0 (same as EEPROM_Write_Offset.ino)
- **Data type:** uint16_t (0-65535 steps)

## Version History

- **1.0.7:** Fixed offset calculation to account for starting flap position, always calculates forward distance to blank flap
- **1.0.6:** Fixed offset calculation to be blank flap position + half steps per flap
- **1.0.5:** Fixed offset calculation to correctly measure steps per flap and blank flap position
- **1.0.4:** Limited to 5 measurements, ignore first 2 if outliers, filter outliers
- **1.0.3:** Changed slow movement to continue until user presses Enter
- **1.0.2:** Improved homing function with better logic and debug output
- **1.0.1:** Fixed serial initialization issues
- **1.0.0:** Initial version

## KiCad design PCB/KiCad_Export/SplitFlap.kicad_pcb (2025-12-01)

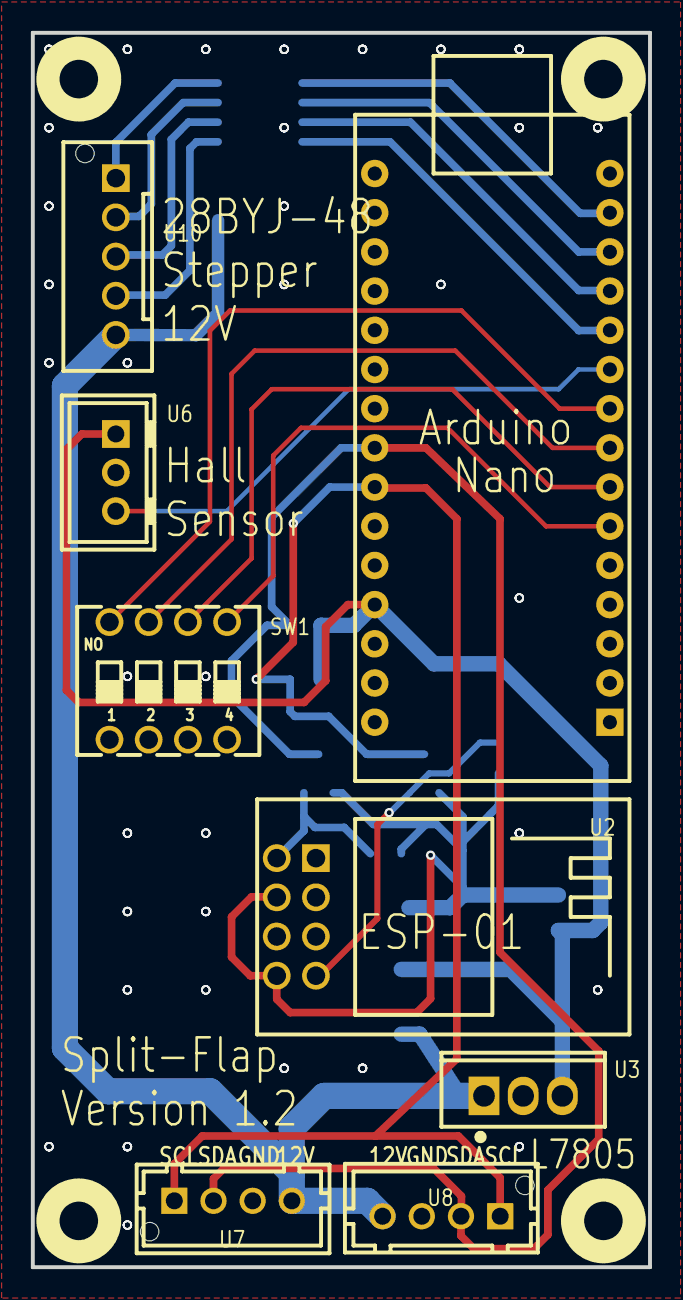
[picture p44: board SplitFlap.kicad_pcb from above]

Board: 2 copper layers, 40.0 x 80.0 mm, 48 parts (0 on the bottom side), 21 nets.

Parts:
C1: 330nF; C0805
C2: 100nF; C0805
C5: 22μF; CAP-SMD_L3.2-W1.6
Q1, Q2: BSS138; SOT-23-3_L2.9-W1.3-P1.90-LS2.4-BR
R1, R2, R3, R4: 10K; R0805
SW1: DSWB04LHGET; SW-TH_DSWB04LHGET
U2: ESP-01S; WIFIM-TH_ESP-01S
U3: L7805CV; TO-220-3_L10.0-W4.5-P2.54-L
U4: ULN2003A; SOP-16_L10.0-W3.9-P1.27-LS6.0-BL
U6: B3B-XH-A(LF)(SN); CONN-TH_3P-P2.50_B3B-XH-A-LF-SN
U7, U8: B4B-XH-AM(LF)(SN); CONN-TH_B4B-XH-AM-LF-SN
U9: AMS1117-3.3; SOT-223-3_L6.5-W3.4-P2.30-LS7.0-BR
U10: B5B-XH-AM (LF)(SN); CONN-TH_B5B-XH-AM-LF-SN
gge2518: hole_0.91_mm; TH_pad_gge2518
gge2533: hole_0.91_mm; TH_pad_gge2533
gge2548: hole_0.91_mm; TH_pad_gge2548
gge2563: hole_0.91_mm; TH_pad_gge2563
gge2578: hole_0.91_mm; TH_pad_gge2578
gge2596: hole_0.91_mm; TH_pad_gge2596
gge2611: hole_0.91_mm; TH_pad_gge2611
gge2626: hole_0.91_mm; TH_pad_gge2626
gge2641: hole_0.91_mm; TH_pad_gge2641
gge2656: hole_0.91_mm; TH_pad_gge2656
gge2674: hole_0.91_mm; TH_pad_gge2674
gge2689: hole_0.91_mm; TH_pad_gge2689
gge2707: hole_0.91_mm; TH_pad_gge2707
gge2722: hole_0.91_mm; TH_pad_gge2722
gge2737: hole_0.91_mm; TH_pad_gge2737
gge2752: hole_0.91_mm; TH_pad_gge2752
gge2767: hole_0.91_mm; TH_pad_gge2767
gge2782: hole_0.91_mm; TH_pad_gge2782
gge2797: hole_0.91_mm; TH_pad_gge2797
gge2812: hole_0.91_mm; TH_pad_gge2812
gge2827: hole_0.91_mm; TH_pad_gge2827
gge2845: hole_0.91_mm; TH_pad_gge2845
gge2860: hole_0.91_mm; TH_pad_gge2860
gge2875: hole_0.91_mm; TH_pad_gge2875
gge2890: hole_0.91_mm; TH_pad_gge2890
gge2905: hole_0.91_mm; TH_pad_gge2905
gge2920: hole_0.91_mm; TH_pad_gge2920
gge2935: hole_0.91_mm; TH_pad_gge2935
gge2950: hole_0.91_mm; TH_pad_gge2950
gge2968: hole_0.91_mm; TH_pad_gge2968

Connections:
+3.3V: C5.1, Q1.1, Q2.1, R1.2, R3.2, U2.5, U2.7, U9.2, U9.4
+5V: C2.1, R2.2, R4.2, U3.3, U6.1, U9.3, gge2797.1
GND: C1.2, C2.2, C5.2, SW1.5, SW1.6, SW1.7, SW1.8, U2.1, U3.2, U4.8, U6.2, U7.3, U8.3, U9.1, gge2563.1, gge2767.1
Q1_2: Q1.2, R1.1, U2.4
Q2_2: Q2.2, R3.1, U2.8
U1_6: SW1.4, gge2596.1
U1_7: SW1.3, gge2611.1
U1_8: SW1.2, gge2626.1
U1_9: SW1.1, gge2641.1
U1_10: U6.3, gge2656.1
U1_11: U4.4, gge2674.1
U1_12: U4.3, gge2689.1
U1_13: U4.2, gge2707.1
U1_14: U4.1, gge2722.1
U1_23: Q2.3, R4.1, U7.2, U8.2, gge2860.1
U1_24: Q1.3, R2.1, U7.1, U8.1, gge2845.1
U4_13: U4.13, U10.4
U4_14: U4.14, U10.3
U4_15: U4.15, U10.2
U4_16: U4.16, U10.1
VCC: C1.1, U3.1, U4.9, U7.4, U8.4, U10.5

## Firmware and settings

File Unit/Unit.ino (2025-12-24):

/*********
  Split Flap Arduino Nano Unit
  Version: 1.2.0
  Changes: Forward-only rotation - all backward movements replaced with forward wrap-around to prevent mechanical issues
  
  Version History:
  - 1.2.0: Forward-only rotation - replaced all backward movements with forward wrap-around, updated calibration to use forward-only positioning
  - 1.1.1: Fixed calibration to move away from marker if already at it on startup (prevents double offset), added trigger width measurement and center positioning
  - 1.1.0: Added expanded I2C status codes (0=ready, 1=busy, 2=cal_searching, 3=cal_offset, 4=cal_error, -1=sleeping)
  
  Major Changes from Scientress Fork:
  - Expanded I2C status reporting: Units now report detailed calibration states (searching, applying offset, errors)
  - Improved serial debugging: Added delay after Serial.begin() to prevent garbled characters, added timestamps to all serial output
  - Version tracking: Added firmware version number for easier debugging and verification
  - Simplified calibration code: Removed excessive debug logging to match original working version
  - Fixed calibration startup: Handles case where unit reboots while already at marker position
*********/

//#define SERIAL_ENABLE // uncomment for serial debug communication
//#define TEST_ENABLE   // uncomment for Test mode. Rotates through a few character to make sure unit is working. These characters should be displayed in the correct order: " ", "Z", "A", "U", "N", "?", "0", "1", "2", "9"

#include <Arduino.h>
#include <Wire.h>
#include <Stepper.h>
#include <EEPROM.h>
#include <avr/sleep.h>

// Pins of I2C adress switch
#define ADRESSSW1 6
#define ADRESSSW2 5
#define ADRESSSW3 4
#define ADRESSSW4 3

//constants stepper
#define STEPPERPIN1 11
#define STEPPERPIN2 10
#define STEPPERPIN3 9
#define STEPPERPIN4 8
#define STEPS 2038 //28BYJ-48 stepper, number of steps
#define HALLPIN 7 //Pin of hall sensor
#define AMOUNTFLAPS 45

//constants others
#define BAUDRATE 9600
#define ROTATIONDIRECTION -1 //-1 for reverse direction
#define OVERHEATINGTIMEOUT 2 //timeout in seconds to avoid overheating of stepper. After starting rotation, the counter will start. Stepper won't move again until timeout is passed
unsigned long lastRotation = 0;

#ifdef SERIAL_ENABLE
//Serial input stuff
const byte numChars = 32;
char receivedChars[numChars]; // an array to store the received data
boolean newData = false;
#endif

//globals
int displayedLetter = 0; //currently shown letter
int desiredLetter = 0; //letter to be shown
const char letters[] = {' ', 'A', 'B', 'C', 'D', 'E', 'F', 'G', 'H', 'I', 'J', 'K', 'L', 'M', 'N', 'O', 'P', 'Q', 'R', 'S', 'T', 'U', 'V', 'W', 'X', 'Y', 'Z', 'Ä', 'Ö', 'Ü', '0', '1', '2', '3', '4', '5', '6', '7', '8', '9', ':', '.', '-', '?', '!'};
Stepper stepper(STEPS, STEPPERPIN1, STEPPERPIN3, STEPPERPIN2, STEPPERPIN4); //stepper setup
bool lastInd1 = false; //store last status of phase
bool lastInd2 = false; //store last status of phase
bool lastInd3 = false; //store last status of phase
bool lastInd4 = false; //store last status of phase
float missedSteps = 0; //cummulate steps <1, to compensate via additional step when reaching >1
int currentlyrotating = 0; // Status codes: 0=ready, 1=busy/moving, 2=calibrating(searching), 3=calibrating(offset), 4=calibration_error, -1=sleeping
int stepperSpeed = 10; //current speed of stepper, value only for first homing
int eeAddress = 0;   //EEPROM address for calibration offset
uint16_t calOffset;       //Offset for calibration in steps, stored in EEPROM, gets read in setup
int receivedNumber = 0;
int i2cAddress;

//sleep globals
const unsigned long WAIT_TIME = 2000;    //wait time before sleep routine gets executed again in milliseconds
unsigned long previousMillis = 0;       //stores last time sleep was interrupted

//test calibration settings
#if defined(SERIAL_ENABLE) || defined(TEST_ENABLE)
int calLetters[10] = {0, 26, 1, 21, 14, 43, 30, 31, 32, 39};
//int calLetters[10] = {0, 6, 1, 5, 0};

void run_test() {
  stepperSpeed = 12;
  for (int i = 0; i < 10; i++) {
    int currentCalLetter = calLetters[i];
    rotateToLetter(currentCalLetter);
    delay(2000);
  }
}
#endif

#ifdef SERIAL_ENABLE
// Helper function to print timestamp before serial messages
void SerialPrintTimestamp() {
  Serial.print(F("["));
  Serial.print(millis());
  Serial.print(F("ms] "));
}
#endif

//setup
void setup() {
  // i2c adress switch
  pinMode(ADRESSSW1, INPUT_PULLUP);
  pinMode(ADRESSSW2, INPUT_PULLUP);
  pinMode(ADRESSSW3, INPUT_PULLUP);
  pinMode(ADRESSSW4, INPUT_PULLUP);

  //hall sensor
  pinMode(HALLPIN, INPUT);

  i2cAddress = getaddress(); //get I2C Address and save in variable

#ifdef SERIAL_ENABLE
  //initialize serial
  Serial.begin(BAUDRATE);
  delay(100); // Wait for serial port to initialize (helps prevent garbled characters)
  SerialPrintTimestamp();
  Serial.println("starting unit");
  SerialPrintTimestamp();
  Serial.print("Firmware Version: ");
  Serial.println("1.2.0");
  SerialPrintTimestamp();
  Serial.print("I2CAddress: ");
  Serial.println(i2cAddress);
#endif

  //I2C function assignment
  Wire.begin(i2cAddress); //i2c address of this unit
  Wire.onReceive(receiveLetter);//call-function for transfered letter via i2c
  Wire.onRequest(requestEvent); //call-funtion if master requests unit state

  getOffset();     //get calibration offset from EEPROM
  calibrate(true); //home stepper after startup

#ifdef TEST_ENABLE
  // Run test on startup
  run_test();
#endif
}

void loop() {
  unsigned long currentMillis = millis();
  if (currentMillis - previousMillis >= WAIT_TIME) {
#ifdef SERIAL_ENABLE
    // Only log sleep/wake if unit is busy (unusual state) or first few cycles for debugging
    static int sleepCycleCount = 0;
    if (currentlyrotating != 0 || sleepCycleCount < 3) {
      SerialPrintTimestamp();
      Serial.print(F("Going to sleep (currentlyrotating="));
      Serial.print(currentlyrotating);
      Serial.println(F(")"));
    }
    sleepCycleCount++;
#endif
    byte old_ADCSRA = ADCSRA;
    // disable ADC
    ADCSRA = 0;
#ifdef SERIAL_ENABLE
    set_sleep_mode (SLEEP_MODE_IDLE);
#else
    set_sleep_mode (SLEEP_MODE_PWR_DOWN);
#endif
    sleep_enable();
#ifndef SERIAL_ENABLE
    digitalWrite (LED_BUILTIN, LOW); // shuts off LED when starting to sleep, for debugging
#endif
    sleep_cpu ();
#ifndef SERIAL_ENABLE
    digitalWrite (LED_BUILTIN, HIGH); // turns on LED when waking up, for debugging
#endif
    sleep_disable();
    previousMillis = currentMillis; //reset sleep counter
    ADCSRA = old_ADCSRA;

#ifdef SERIAL_ENABLE
    // Only log wake/I2C reinit if unit is busy or first few cycles
    if (currentlyrotating != 0 || sleepCycleCount <= 3) {
      SerialPrintTimestamp();
      Serial.println(F("Woke up from sleep"));
      SerialPrintTimestamp();
      Serial.println(F("I2C reinitialized after sleep"));
    }
#endif
    // release TWI bus
    TWCR = bit(TWEN) | bit(TWIE) | bit(TWEA) | bit(TWINT);

    // turn it back on again
    Wire.begin (i2cAddress);
  }  // end of time to sleep

  //check if new letter was received through i2c
  if (displayedLetter != receivedNumber)
  {
    /*
      #ifdef SERIAL_ENABLE
      SerialPrintTimestamp();
      Serial.print("Value over serial received: ");
      Serial.print(receivedNumber);
      Serial.print(" Letter: ");
      Serial.print(letters[receivedNumber]);
      Serial.println();
      #endif
    */
    //rotate to new letter
    rotateToLetter(receivedNumber);
  }

#ifdef SERIAL_ENABLE
  // check if we got calibration data via serial
  recvWithEndMarker();
#endif
}

int translateLettertoInt(char letterchar) {
  // automatically convert lower case to upper case
  if ('a' <= letterchar && letterchar <= 'z') {
    letterchar -= 32;
  }
  for (int flapIndex = 0; flapIndex < sizeof(letters); flapIndex++) {
    if (letterchar == letters[flapIndex]) {
      return flapIndex;
    }
  }

  return -1;
}

//rotate to letter
void rotateToLetter(int toLetter) {
  if (lastRotation == 0 || (millis() - lastRotation > OVERHEATINGTIMEOUT * 1000)) {
    lastRotation = millis();
    //get letter position
    int posLetter = -1;
    posLetter = toLetter;
    int posCurrentLetter = -1;
    posCurrentLetter = displayedLetter;
    //int amountLetters = sizeof(letters) / sizeof(String);
#ifdef SERIAL_ENABLE
    SerialPrintTimestamp();
    Serial.print(F("go to letter: "));
    Serial.println(letters[toLetter]);
#endif
    //go to letter, but only if available (>-1)
    if (posLetter > -1) { //check if letter exists
      bool motorStarted = false;
      //check if letter is on higher index, then no full rotaion is needed
      if (posLetter >= posCurrentLetter) {
#ifdef SERIAL_ENABLE
        SerialPrintTimestamp();
        Serial.println("direct");
#endif
        //go directly to next letter, get steps from current letter to target letter
        int diffPosition = posLetter - posCurrentLetter;
        startMotor();
        motorStarted = true;
        stepper.setSpeed(stepperSpeed);
        //doing the rotation letterwise
        for (int i = 0; i < diffPosition; i++) {
          float preciseStep = (float)STEPS / (float)AMOUNTFLAPS;
          int roundedStep = (int)preciseStep;
          missedSteps = missedSteps + ((float)preciseStep - (float)roundedStep);
          if (missedSteps > 1) {
            roundedStep = roundedStep + 1;
            missedSteps--;
          }
          stepper.step(ROTATIONDIRECTION * roundedStep);
        }
      }
      else {
        //full rotation is needed, good time for a calibration
#ifdef SERIAL_ENABLE
        SerialPrintTimestamp();
        Serial.println(F("full rotation incl. calibration"));
#endif
        startMotor(); // Ensure motor is started before calibration
        motorStarted = true;
        int calResult = calibrate(false); //calibrate revolver and do not stop motor
        if (calResult < 0) {
          // Calibration failed - stop motor and reset status to prevent getting stuck
          stopMotor();
          return; // Exit early if calibration failed
        }
        stepper.setSpeed(stepperSpeed);
        for (int i = 0; i < posLetter; i++) {
          float preciseStep = (float)STEPS / (float)AMOUNTFLAPS;
          int roundedStep = (int)preciseStep;
          missedSteps = missedSteps + (float)preciseStep - (float)roundedStep;
          if (missedSteps > 1) {
            roundedStep = roundedStep + 1;
            missedSteps--;
          }
          stepper.step(ROTATIONDIRECTION * roundedStep);
        }
      }
      //store new position
      displayedLetter = toLetter;
      //rotation is done, stop the motor (always ensure motor is stopped)
      if (motorStarted) {
        delay(100); //important to stop rotation before shutting of the motor to avoid rotation after switching off current
        stopMotor();
      }
    }
    else {
#ifdef SERIAL_ENABLE
      SerialPrintTimestamp();
      Serial.println("letter unknown, go to space");
#endif
      desiredLetter = 0;
    }
  }
}

void receiveLetter(int numBytes) {
  int receiveArray[4]; //array for received bytes
  uint16_t newCalOffset = 0;

  for (int i = 0; i < numBytes && i < 4; i++) {
    receiveArray[i] = Wire.read();
  }
  //Write received bytes to correct variables
  receivedNumber = receiveArray[0];
  stepperSpeed = receiveArray[1];
  if (numBytes >= 4) {
    newCalOffset = receiveArray[2] + (receiveArray[3] << 8);
    if (newCalOffset != calOffset) {
      calOffset = newCalOffset;
      writeToEEPROM(calOffset);
    }
  }
}

void requestEvent() {
#ifdef SERIAL_ENABLE
  SerialPrintTimestamp();
  Serial.print(F("Status request received - sending: "));
  Serial.print(currentlyrotating);
  Serial.print(F(" (0=ready, 1=busy, 2=cal_searching, 3=cal_offset, 4=cal_error, -1=sleeping)"));
  Serial.print(F(" | displayedLetter: "));
  Serial.print(displayedLetter);
  Serial.print(F(" | receivedNumber: "));
  Serial.println(receivedNumber);
#endif
  Wire.write(currentlyrotating); //send unit status to master
}

//returns the adress of the unit as int from 0-15
int getaddress() {
  int address = !digitalRead(ADRESSSW4) + (!digitalRead(ADRESSSW3) * 2) + (!digitalRead(ADRESSSW2) * 4) + (!digitalRead(ADRESSSW1) * 8);
  return address;
}

//gets magnet sensor offset from EEPROM in steps
void getOffset() {
  EEPROM.get(eeAddress, calOffset);
  if (calOffset < 0) {
    calOffset = 0;
  }
#ifdef SERIAL_ENABLE
  SerialPrintTimestamp();
  Serial.print(F("CalOffset from EEPROM: "));
  Serial.print(calOffset);
  Serial.print(F(" (raw value from EEPROM)"));
  Serial.println();
  SerialPrintTimestamp();
  Serial.print(F("EEPROM address: "));
  Serial.print(eeAddress);
  Serial.println();
  SerialPrintTimestamp();
  Serial.print(F("Offset will be applied as: "));
  Serial.print(ROTATIONDIRECTION);
  Serial.print(F(" * "));
  Serial.print(calOffset);
  Serial.print(F(" = "));
  Serial.print(ROTATIONDIRECTION * calOffset);
  Serial.print(F(" steps ("));
  Serial.print(ROTATIONDIRECTION * calOffset > 0 ? F("forward") : F("backward"));
  Serial.println(F(")"));
#endif
}

//doing a calibration of the revolver using the hall sensor
int calibrate(bool initialCalibration) {
#ifdef SERIAL_ENABLE
  SerialPrintTimestamp();
  Serial.println(F("calibrate revolver"));
  unsigned long calStartTime = millis();
  int lastLogStep = -1000; // Track last logged step to avoid spamming
#endif
  currentlyrotating = 2; // Status: calibrating (searching for marker)
  bool reachedMarker = false;
  stepper.setSpeed(stepperSpeed);
  int i = 0;
  while (!reachedMarker) {
    int currentHallValue = digitalRead(HALLPIN);
    
#ifdef SERIAL_ENABLE
    // Log progress every 500 steps or at key moments
    if (i - lastLogStep >= 500 || i == 0 || i == 50 || (i % 1000 == 0)) {
      unsigned long elapsed = millis() - calStartTime;
      SerialPrintTimestamp();
      Serial.print(F("Step: "));
      Serial.print(i);
      Serial.print(F(" / "));
      Serial.print(3 * STEPS);
      Serial.print(F(" | Hall: "));
      Serial.print(currentHallValue);
      Serial.print(F(" (1=no magnet, 0=magnet) | Time: "));
      Serial.print(elapsed);
      Serial.println(F("ms"));
      lastLogStep = i;
    }
    // Also log when Hall sensor changes state (important for debugging)
    static int lastHallValue = -1;
    if (currentHallValue != lastHallValue) {
      SerialPrintTimestamp();
      Serial.print(F("Hall sensor changed: "));
      Serial.print(lastHallValue);
      Serial.print(F(" -> "));
      Serial.print(currentHallValue);
      Serial.print(F(" at step "));
      Serial.print(i);
      Serial.println();
      lastHallValue = currentHallValue;
    }
#endif
    
    if (i == 0) {
      // At start of calibration - check initial Hall sensor state
      if (currentHallValue == 0) {
        // Already at marker position at startup - move away first to ensure we find it properly
        // This prevents double-applying offset if unit reboots while already homed
#ifdef SERIAL_ENABLE
        SerialPrintTimestamp();
        Serial.println(F("Already at marker at startup, moving 50 steps away to re-find it"));
#endif
        i = 50;
        stepper.step(ROTATIONDIRECTION * 50); //move 50 steps in normal rotation direction
        // Continue loop - next iteration will check Hall sensor again after moving
        i++; // Increment so we don't hit this check again
        continue; // Re-check Hall sensor after moving away
      }
      // If Hall == 1 at startup, that's normal - continue with normal search below
    }
    
    if (currentHallValue == 1) {
      //not reached yet - still searching for marker
      currentlyrotating = 2; // Keep status as "calibrating (searching)"
      stepper.step(ROTATIONDIRECTION * 1); // Normal rotation direction only
    }
    else if (currentHallValue == 0 && i > 0) {
      //reached marker LEADING EDGE (and we've moved at least 1 step, so we found it properly)
      // The i > 0 check ensures we didn't just start at the marker (prevents double offset)
      // STOP HERE IMMEDIATELY - this is the marker edge position (leading edge, start of magnet)
      // This matches the calibration tool which calculates offset from the leading edge
      // We do NOT move forward to measure trigger width - we stop immediately at the leading edge
      
#ifdef SERIAL_ENABLE
      unsigned long markerFoundTime = millis() - calStartTime;
      SerialPrintTimestamp();
      Serial.print(F("*** MARKER FOUND *** at step: "));
      Serial.print(i);
      Serial.print(F(" | Time: "));
      Serial.print(markerFoundTime);
      Serial.println(F("ms - Stopped at leading edge (start of magnet)"));
      SerialPrintTimestamp();
      Serial.println(F("(Staying at leading edge - no forward movement to measure trigger width)"));
#endif
      
      reachedMarker = true;
      currentlyrotating = 3; // Status: calibrating (applying offset)
      
#ifdef SERIAL_ENABLE
      SerialPrintTimestamp();
      Serial.print(F("Marker edge found at step: "));
      Serial.println(i);
      SerialPrintTimestamp();
      Serial.print(F("CalOffset value from EEPROM: "));
      Serial.print(calOffset);
      Serial.println(F(" steps"));
      
      if (calOffset == 0) {
        SerialPrintTimestamp();
        Serial.println(F("WARNING: CalOffset is ZERO! Offset will not be applied."));
        SerialPrintTimestamp();
        Serial.println(F("This means either:"));
        SerialPrintTimestamp();
        Serial.println(F("  1. EEPROM was never written (calibration not done)"));
        SerialPrintTimestamp();
        Serial.println(F("  2. EEPROM was cleared"));
        SerialPrintTimestamp();
        Serial.println(F("  3. EEPROM read failed"));
        SerialPrintTimestamp();
        Serial.println(F("Unit will stay at marker edge position (not at blank flap center)"));
      } else {
        SerialPrintTimestamp();
        Serial.print(F("ROTATIONDIRECTION: "));
        Serial.println(ROTATIONDIRECTION);
        SerialPrintTimestamp();
        Serial.print(F("Calculated step value: "));
        Serial.print(ROTATIONDIRECTION);
        Serial.print(F(" * "));
        Serial.print(calOffset);
        Serial.print(F(" = "));
        long stepValue = (long)ROTATIONDIRECTION * (long)calOffset;
        Serial.print(stepValue);
        Serial.println(F(" steps"));
        SerialPrintTimestamp();
        Serial.print(F("Applying offset: moving "));
        Serial.print(abs(stepValue));
        Serial.print(F(" steps "));
        Serial.print(stepValue > 0 ? F("forward") : F("backward"));
        Serial.println();
      }
#endif
      
      // Apply offset: calOffset is steps in ROTATIONDIRECTION, just like scientress version
      // Apply directly - no conversion needed, no wrap-around
      // ROTATIONDIRECTION = -1, so ROTATIONDIRECTION * calOffset moves in ROTATIONDIRECTION
      long markerStep = i; // Save marker position before offset
      long stepValue = 0;
      if (calOffset > 0) {
        stepValue = (long)ROTATIONDIRECTION * (long)calOffset;
        stepper.step(stepValue); // Normal rotation direction only
        i = i + stepValue;
      } else {
        // Offset is zero - don't move, stay at marker
        stepValue = 0;
        // i stays at marker position
      }
      // Wrap around if negative (shouldn't happen, but handle it)
      if (i < 0) {
#ifdef SERIAL_ENABLE
        SerialPrintTimestamp();
        Serial.print(F("WARNING: Step counter went negative ("));
        Serial.print(i);
        Serial.println(F("), wrapping around"));
#endif
        i = i + STEPS;
      }
      // Wrap around if beyond one rotation
      if (i >= STEPS) {
#ifdef SERIAL_ENABLE
        SerialPrintTimestamp();
        Serial.print(F("WARNING: Step counter exceeded STEPS ("));
        Serial.print(i);
        Serial.println(F("), wrapping around"));
#endif
        i = i - STEPS;
      }
      
      displayedLetter = 0;
      missedSteps = 0;
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

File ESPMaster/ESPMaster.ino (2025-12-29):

/* ####################################################################################################################### */
/* # ____  ____  _     ___ _____   _____ _        _    ____    _____ ____  ____    __  __    _    ____ _____ _____ ____  # */
/* #/ ___||  _ \| |   |_ _|_   _| |  ___| |      / \  |  _ \  | ____/ ___||  _ \  |  \/  |  / \  / ___|_   _| ____|  _ \ # */
/* #\___ \| |_) | |    | |  | |   | |_  | |     / _ \ | |_) | |  _| \___ \| |_) | | |\/| | / _ \ \___ \ | | |  _| | |_) |# */
/* # ___) |  __/| |___ | |  | |   |  _| | |___ / ___ \|  __/  | |___ ___) |  __/  | |  | |/ ___ \ ___) || | | |___|  _ < # */
/* #|____/|_|   |_____|___| |_|   |_|   |_____/_/   \_|_|     |_____|____/|_|     |_|  |_/_/   \_|____/ |_| |_____|_| \_\# */
/* ####################################################################################################################### */
/*
  This project project is done for fun as part of: https://github.com/JonnyBooker/split-flap
  None of this would be possible without the brilliant work of David Königsmann: https://github.com/Dave19171/split-flap

  Licensed under GNU: https://github.com/JonnyBooker/split-flap/blob/master/LICENSE
  
  Modified by Scott - Added LED debug codes and non-blocking operations for better web server responsiveness
  
  Version: 1.1.22
  Changes: Added I2C setup scan system for comprehensive bus testing
           - Created ServiceI2CSetupScan.ino that scans all 16 possible I2C addresses (0-15)
           - Tests both read and write operations for each found device
           - Reports which addresses are working, read-only, write-only, or not working
           - Compares found devices against expected units (0 to UNITS_AMOUNT-1)
           - Identifies unexpected devices (misconfigured address switches)
           - Added I2C_SETUP_SCAN_ENABLE flag (default: true) for startup scanning
           - Added /i2c-setup-scan endpoint for on-demand testing
           - Perfect for testing individual units before connecting them all
           - Each unit keeps its configured ID number (no renumbering needed)
  
  Version: 1.1.21
  Changes: Added optional I2C diagnostic testing system
           - Created ServiceI2CDiagnostics.ino with comprehensive read/write/speed tests
           - Added I2C_DIAGNOSTIC_ENABLE flag (default: false) for startup testing
           - Added /i2c-diagnostics endpoint for on-demand testing (works even if flag is false)
           - Can test specific unit (?unit=7) or all units
           - Tests: address detection, read operations, write operations, error rate
           - Safe to enable/disable without affecting normal operation
  
  Major Changes from Scientress Fork:
  - Expanded I2C status codes: ESPMaster now interprets detailed unit calibration states for better debugging
  - Enhanced calibration wait loop: Improved timeout handling, stuck unit detection, and progress logging
  - Improved error handling: Better I2C error reporting and unit status tracking during calibration
  - Version tracking: Added firmware version number for easier debugging and verification
  - ESP-01S support: Better handling of ESP-01S vs ESP-01 differences (LED, I2C initialization)
  - Serial/I2C conflict handling: Proper initialization to avoid GPIO 1 conflicts on ESP-01
*/

/* .--------------------------------------------------------------------------------. */
/* |  ___           __ _                    _    _       ___       __ _             | */
/* | / __|___ _ _  / _(_)__ _ _  _ _ _ __ _| |__| |___  |   \ ___ / _(_)_ _  ___ ___| */
/* || (__/ _ | ' \|  _| / _` | || | '_/ _` | '_ | / -_) | |) / -_|  _| | ' \/ -_(_-<| */
/* | \___\___|_||_|_| |_\__, |\_,_|_| \__,_|_.__|_\___| |___/\___|_| |_|_||_\___/__/| */
/* |                    |___/                                                       | */
/* '--------------------------------------------------------------------------------' */
/*
  These define statements can be changed as you desire for changing the functionality and
  behaviour of your device.
*/
#define SERIAL_ENABLE       false   //Option to enable serial debug messages
#define UNIT_CALLS_DISABLE  false   //Option to disable the call to the units so can just debug the ESP with no connections
#define OTA_ENABLE          true    //Option to enable OTA functionality
#define UNITS_AMOUNT        10       //Amount of connected units !IMPORTANT TO BE SET CORRECTLY!
#define SERIAL_BAUDRATE     57600  //Serial debugging BAUD rate
#define WIFI_USE_DIRECT     true   //Option to either direct connect to a WiFi Network or setup a AP to configure WiFi. Setting to false will setup as a AP.
#define ESP01S_LED_ENABLE   true   //Option to enable LED error indication on ESP-01S (set to false if not using ESP-01S or LED)
#define DEBUG_ENABLE        true  //Enable debug features: startup debug page, error status panel, and serial debug log at bottom of page
#define PAGE_LOAD_DEBUG_ENABLE false  //Enable page load debug blocks: browser errors panel and page load debug log at top of page (set to true for troubleshooting page loading issues)
#define I2C_DIAGNOSTIC_ENABLE false  //Enable I2C diagnostic testing (DISABLED by default - blocks web server startup; use /i2c-diagnostics endpoint instead)
#define I2C_SETUP_SCAN_ENABLE false  //Enable I2C setup scan at startup (DISABLED by default - blocks web server startup; use /i2c-setup-scan endpoint instead)
#define CLOCK_FORMAT_24H false  //Default clock format: true = 24-hour (HH:MM), false = 12-hour (hh:mma)

/*
  EXPERIMENTAL: Try to use your Router when possible to set a Static IP address for your device to avoid conflicts with other devices
  on your network. This will try and setup your device with a static IP address of your chosing. See below for more details.
*/
#define WIFI_STATIC_IP      true
//#define FAE_MOD                   //Option for the modified PCB that includes an ESP-12F module

// LED Debug Pin Configuration for ESP-01S
// ESP-01S has an onboard blue LED on GPIO 2 (not on TX/RX lines), which is active LOW.
// This allows the LED to be used for error indication while keeping TX/RX lines
// dedicated to I2C communication with the split-flap units.
// Note: This feature only works with ESP-01S. The original ESP-01 has its LED on GPIO 1 (TX),
// which conflicts with I2C communication, so this LED feature is not supported on ESP-01.
#define LED_DEBUG_PIN 2  // GPIO 2 = onboard blue LED on ESP-01S
#define LED_ON LOW       // ESP-01S onboard LED is active LOW
#define LED_OFF HIGH

/*
  LED ERROR INDICATION:
  The LED will continuously blink when an error is detected (e.g., WiFi connection failed).
  This provides a simple visual indicator for critical errors.
*/
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

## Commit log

2025-11-27 Major updates to support new Arduino version.
    [Assembly.step, BackCoverCenter.stl, BackCoverLeft.stl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]
2025-11-28 Working version. Adding new calibration routine.
    [Split-Flap_Assembly - BigRotor.stl, Split-Flap_Assembly - MiniRotor.stl]
2025-12-01 Latest updates
    [Gerber_BoardOutline.GKO, Gerber_BottomLayer.GBL, Gerber_BottomPasteMaskLayer.GBP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]
2025-12-11 Update Unit and InteractiveCalibration firmware to version 1.2.0 and 1.0.21 respectively. Implemented forward-only rotation in Unit.ino to prevent mechanical issues and updated calibration logic to s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
    [InteractiveCalibration.ino, Unit.ino]
2025-12-22 Fix web server startup blocking and add unit testing interface
    - Remove blocking I2C scans and calibration wait from startup to allow immediate web server response
    - Add unit testing table on main page with individual unit test buttons
    - Simplify debug page to just show status and continue button
    - Add I2C diagnostic and setup scan services (ServiceI2CDiagnostics.ino, ServiceI2CSetupScan.ino)
    - Add on-demand I2C scan button on main page
    - Update documentation for LittleFS upload instructions
    - Web server now starts immediately, units calibrate in background
    [ESPMaster.ino, ServiceI2CDiagnostics.ino, ServiceI2CSetupScan.ino]
2025-12-23 update for new Arduino version > 2
2025-12-24 Working version! queries work, and fixes for interactive calibration.
    [ESPMaster.ino, InteractiveCalibration.ino, Unit.ino]
2025-12-29 train station functions and more.
    [Split Flap - Temporary Foot.step, Split-Flap_Assembly - Frame.step]
